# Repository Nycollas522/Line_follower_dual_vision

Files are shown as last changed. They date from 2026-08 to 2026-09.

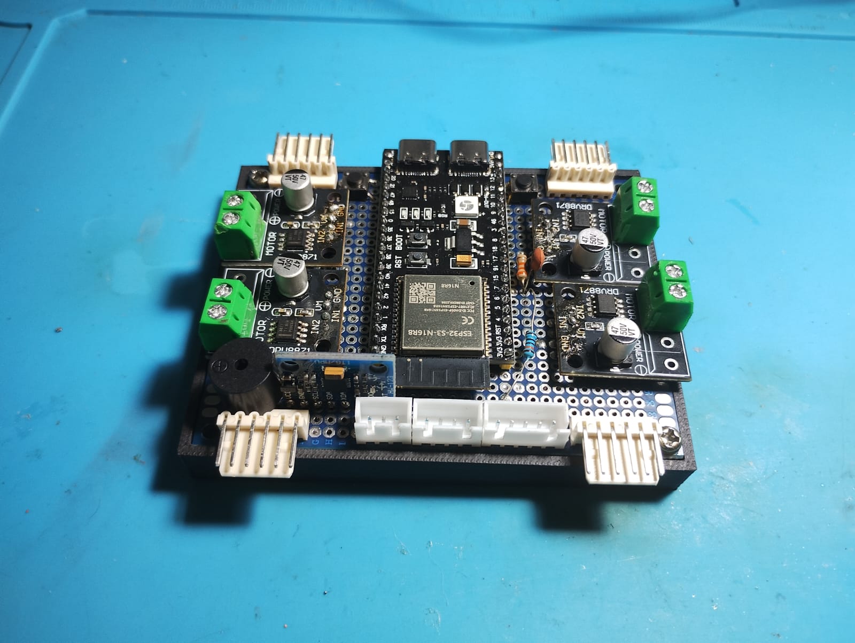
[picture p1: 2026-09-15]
Eletronica/Placa_Inicial/PCB_Superior.jpeg

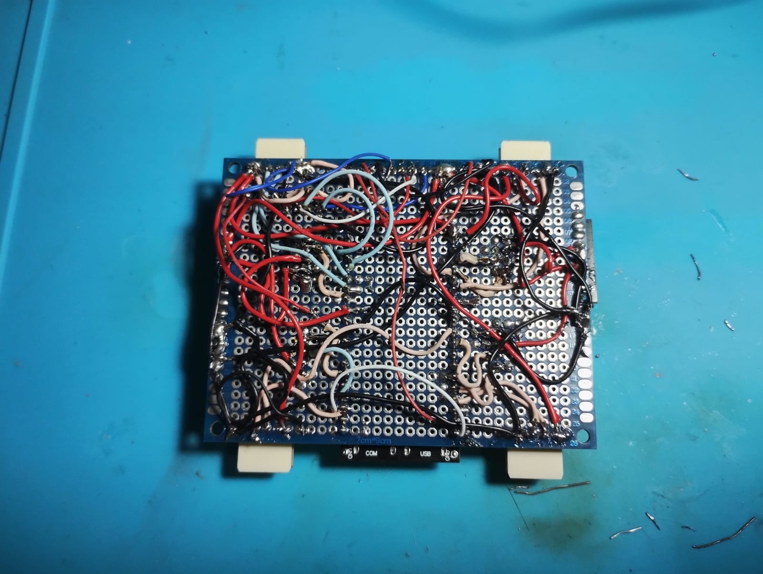
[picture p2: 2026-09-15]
Eletronica/Placa_Inicial/PCB_Inferior.jpeg

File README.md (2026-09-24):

# Line Follower — Visão Dupla

Robô seguidor de linha com **chassi mecanum 4x4** e **duas câmeras**:
uma inferior apontada para o chão, que é a percepção primária do laço
rápido, e uma superior num servo, que serve de aviso antecipado de
curva.

O processamento é dividido em dois: a **Raspberry Pi 5** roda visão e
controle em ROS 2 Jazzy; o **ESP32-S3** fecha o laço de velocidade de
cada roda a 100 Hz e é quem corta os motores se a comunicação cair.

---

## Organização

| pasta | conteúdo |
|---|---|
| **[`Softwares/`](Softwares/)** | Firmware do ESP32-S3 e a pilha ROS 2. Para operar: [guia de operação](Softwares/ros2_ws/OPERACAO.md). Arquitetura e histórico: [README técnico](Softwares/ros2_ws/README.md). |
| [`Eletronica/`](Eletronica/) | Placas e esquemáticos |
| [`Mecanica/`](Mecanica/) | Chassi e modelos CAD |

---

## Especificações

### Chassi

| grandeza | valor |
|---|---|
| Entre-eixos | 176 mm |
| Bitola | 154 mm |
| Diâmetro da roda mecanum | 78 mm |
| Raio mínimo de arco | 165 mm |

### Eletrônica

- **Raspberry Pi 5** — visão e controle (ROS 2 Jazzy)
- **ESP32-S3** — controle de baixo nível, PID por roda a 100 Hz
- 2× câmera CSI (OV5647)
- Servo de pan para a câmera superior
- IMU MPU6050 e display OLED SSD1306
- Bateria LiPo 3S

### Percepção

A **câmera inferior** aponta reto para baixo, 132 mm à frente do centro
cinemático. A vista é ortográfica: a fita mede a mesma largura em toda a
profundidade do quadro, o que simplifica a calibração e torna o erro
lateral uma medida direta em milímetros.

A **câmera superior** enxerga de 20,5 a 54,5 cm à frente. Ela **não** é
referência de direção — é sensor de aviso: nas corridas instrumentadas
antecipou 17 de 23 quebras, com 1,5 a 3,4 s de folga.

---

## Modos de operação

Escolhidos no **menu do OLED do ESP32**. Como a Pi sobe sozinha no boot,
essa é a única interface que existe sem um PC por perto.

| modo | quem dirige | percepção | câmeras |
|---|---|---|---|
| **Parado** | ninguém | desligada | publicando |
| **Seguidor** | seguidor de linha | ligada | publicando |
| **RC** | joystick (DualShock 4) | desligada | publicando |

As câmeras publicam nos três modos de propósito: permite acompanhar a
imagem por `rqt` de um PC externo mesmo dirigindo na mão.

> Escolher um modo **nunca arma a autonomia**. Modo diz quem tem
> autoridade; armar é um ato separado.

Trocar de modo pelo ROS, perfis de velocidade (SUAVE / MÉDIA / RÁPIDA) e o
resto da operação: [guia de operação](Softwares/ros2_ws/OPERACAO.md).

---

## Resultados medidos

Corrida de 3 minutos na pista, com telemetria completa
([dados](Softwares/ros2_ws/dados/)):

```
21,1 m percorridos          99,77% de quadros válidos
erro lateral mediano 8,4 mm       perdas: 0,41 s (0,23% do tempo)
19 quebras atravessadas, 2 travadas
```

### O limite físico das quebras

Uma quebra de ângulo Δ exige um desvio lateral de `R·(1/cos(Δ/2) − 1)`,
onde `R` é o raio mínimo de arco. Somando o erro de rastreio típico e
comparando com a margem lateral da câmera, sai um **limite de 57,8°**.

Validado em duas corridas independentes: **toda** quebra acima desse
ângulo travou, e nenhuma abaixo dele travou na primeira corrida.
Levantar a câmera inferior de 87 para 110 mm elevaria o limite para
70,1° — é margem lateral, não potência, que limita a curva.

---

## Rodando

No robô, a pilha **sobe sozinha no boot** (`robo.service`) em modo Parado.
Ligar, parar, reiniciar, trocar de modo, rodar uma corrida e resetar:
**[guia de operação](Softwares/ros2_ws/OPERACAO.md)**.

Primeira instalação (workspace novo):

```bash
cd Softwares/ros2_ws
colcon build --symlink-install
source install/setup.bash
ros2 launch robot_bringup line_follower.launch.py serial:=true   # so sem o robo.service no ar
```

> ⚠️ **Este robô anda de verdade.** Antes de armar a autonomia, garanta
> espaço livre e saiba como pará-lo
> ([guia, seção 1](Softwares/ros2_ws/OPERACAO.md#1-parar-o-robô-agora)).

O [guia completo](Softwares/ros2_ws/README.md) tem calibração geométrica,
tabela de diagnóstico sintoma → causa → ajuste, as armadilhas já
descobertas nesta bancada e o histórico de correções com os números que
as motivaram.

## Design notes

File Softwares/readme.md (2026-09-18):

# Softwares

Todo o software do robô: firmware do ESP32-S3 e a pilha ROS 2 da
Raspberry Pi.

| pasta | o que é |
|---|---|
| **[`Firmware_Ippo/`](Firmware_Ippo/)** | Firmware do ESP32-S3 (PlatformIO/Arduino). Controle das rodas a 100 Hz, PID por roda, odometria com IMU, menu no OLED, protocolo serial. |
| **[`ros2_ws/`](ros2_ws/)** | Pilha ROS 2 Jazzy. Percepção das duas câmeras, controlador do seguidor, ponte serial, servo da cabeça, modo RC por joystick. |
| **[`ros2_ws/README.md`](ros2_ws/README.md)** | **Guia completo de operação e depuração.** Comece por aqui. |
| [`ros2_ws/dados/`](ros2_ws/dados/) | CSVs de corrida que sustentam os números citados na documentação. |
| [`Codigos_antigos/`](Codigos_antigos/) | Versões anteriores, só como registro. Nada aqui roda no robô atual. |

> ⚠️ **Este robô anda de verdade.** Antes de habilitar a autonomia,
> garanta espaço livre e saiba onde está o STOP. Veja a seção
> "Parar tudo, agora" no guia.

## Em um parágrafo

Chassi mecanum 4x4. A **câmera inferior** aponta reto para baixo e é a
percepção primária do laço rápido; a **superior** fica num servo e serve
de aviso antecipado de curva, não de referência de direção. A Raspberry
Pi roda a visão e o controle; o **ESP32-S3** fecha o laço de velocidade
de cada roda a 100 Hz e é quem corta os motores se a comunicação cair.

O modo de operação (**parado / seguidor / RC**) é escolhido no **menu do
OLED do ESP32** — com o Pi subindo sozinho no boot, essa é a única
interface que existe sem um PC por perto.

## Estrutura mínima para rodar

```bash
cd ros2_ws
colcon build --symlink-install
source install/setup.bash
ros2 launch robot_bringup line_follower.launch.py serial:=true
```

O guia em [`ros2_ws/README.md`](ros2_ws/README.md) tem o resto: calibração
geométrica, tabela de diagnóstico sintoma → causa → ajuste, armadilhas
conhecidas desta bancada e o histórico de correções com os números que
as motivaram.

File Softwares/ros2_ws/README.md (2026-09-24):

# Line Follower — Visão Dupla (ROS 2 Jazzy + ESP32)

Robô seguidor de linha com chassi mecanum 4x4, câmera inferior (percepção
primária) + câmera superior em servo (preview/antecipação), controlado por
Raspberry Pi (ROS 2 Jazzy) com interface de baixo nível num ESP32-S3.

> 📘 **Para operar o robô, use o [OPERACAO.md](OPERACAO.md)**: parar,
> ligar/parar/reiniciar a pilha, trocar de modo pelo menu e pelo ROS,
> armar a autonomia, perfil de velocidade, menu do ESP32, resets, gravar
> firmware e calibrações — conferido contra o código em 24/09/2026.
> Este README guarda arquitetura, parâmetros, depuração e histórico; onde
> os dois divergirem, **vale o OPERACAO.md**.

> ⚠️ **Este robô anda de verdade.** Antes de habilitar autonomia, garanta
> espaço livre, esteja de olho no robô e saiba como pará-lo
> ([OPERACAO.md §1](OPERACAO.md#1-parar-o-robô-agora)). O **B1 longo** no
> ESP32 para e trava os motores (firmware de 24/09/2026 em diante).

---

## Sumário

- [**Próxima sessão — checklist**](#próxima-sessão--checklist)
- [Arquitetura em um parágrafo](#arquitetura-em-um-parágrafo)
- [Diagrama de nós e tópicos](#diagrama-de-nós-e-tópicos)
- [Estrutura do repositório](#estrutura-do-repositório)
- [Build](#build)
- [Subir o sistema](#subir-o-sistema)
- [Parar tudo, agora](#parar-tudo-agora)
- [Ligar/desligar autonomia (do jeito confiável)](#ligardesligar-autonomia-do-jeito-confiável)
- [Modo bancada — mexer na cabeça sem o robô sair andando](#modo-bancada--mexer-na-cabeça-sem-o-robô-sair-andando)
- [Modos de operação (escolhidos no menu do ESP32)](#modos-de-operação-escolhidos-no-menu-do-esp32)
- [Ligar sozinho no boot (systemd)](#ligar-sozinho-no-boot-systemd)
- [Modo RC (joystick DualShock 4)](#modo-rc-joystick-dualshock-4)
- [Teleoperação](#teleoperação)
- [Tabela de tópicos](#tabela-de-tópicos)
- [Protocolo serial (Pi ↔ ESP32)](#protocolo-serial-pi--esp32)
- [Parâmetros — referência completa](#parâmetros--referência-completa)
- [Comandos de depuração](#comandos-de-depuração)
- [Scripts de teste prontos](#scripts-de-teste-prontos)
- [Gravar e reproduzir dados (rosbag)](#gravar-e-reproduzir-dados-rosbag)
- [Plano de testes incremental](#plano-de-testes-incremental)
- [Tabela de diagnóstico (sintoma → causa → ajuste)](#tabela-de-diagnóstico-sintoma--causa--ajuste)
- [Armadilhas conhecidas desta stack](#armadilhas-conhecidas-desta-stack)
- [Testes automatizados (pytest)](#testes-automatizados-pytest)
- [Convenções de sinal](#convenções-de-sinal)
- [Geometria e calibração física](#geometria-e-calibração-física)
- [Histórico de correções relevantes](#histórico-de-correções-relevantes)

---

## Próxima sessão — checklist

Estado ao fechar 10/09/2026: **2 voltas completas na pista**, 160 testes
passando, pilha em modo bancada. Últimos dados em
`logs/corrida_20260910_203230.csv`.

### 1. Rodas — o único achado sem explicação (fazer PRIMEIRO)

O lado direito lê **parado 2.3× mais** que o esquerdo quando a cinemática
pede acima de 0.12 m/s:

```
FL   6.08%      FR  12.73%
RL   5.12%      RR  13.38%
```

Não é quantização de encoder (episódios de 200–400 ms, alguns de 1.9 s) e
não é zona morta (é *pior* em 0.12–0.18 m/s do que em 0.05–0.08). Está
**idêntico nas duas corridas de 3 min** (14.67% e 14.58%), então não veio
de nenhuma mudança recente. Este robô já escondeu mau contato em duas
rodas por um dia inteiro.

```bash
# RODAS SUSPENSAS -- isola tração de atrito com o chão. ~2 min.
python3 scripts/teste_rodas.py
```

Não tirar conclusão sem esse teste. O sintoma na pista ("guiada um pouco
mais ruidosa") é fraco demais para acusar hardware sozinho.

### 2. Decidir o limite de quebra

Modelo validado com **n=6 em duas corridas**: toda quebra acima de
**57.8°** travou, e nenhuma abaixo travou na primeira corrida.

```
limite = 2·acos( 1 / ((margem − erro_rastreio)/R + 1) )
R = wheel_base_k / arc_ratio = 0.165 m      erro_rastreio ≈ 8.4 mm (p50)
```

| margem | altura da inferior | limite |
|---|---|---|
| 31.9 mm | 87 mm (hoje) | **57.8°** |
| 45.0 mm | ~110 mm | **70.1°** |

Decisão do operador foi **não** subir a câmera e usar a quebra fechada
como teste de reencontro. Se mudar de ideia, é só remontagem +
recalibração (`depth_*`, `width_*`, `roi_bottom`) — nenhuma linha de
código.

### 3. A superior: aviso, não reencontro

Medido: no vértice a pista **já saiu do campo dela** (20.5 a 54.5 cm à
frente). Virar a cabeça não traz de volta o que não está lá — confirmado
com o robô parado na quebra, inferior lendo +21.4° com 5/5 bandas e a
superior em SEM LINHA com a cabeça em +15.4°.

Onde ela ganha o lugar dela: **avisou 17 de 23 quebras, 1.5 a 3.4 s
antes**. Planejar em cima disso, não de reencontro no vértice.

Se for investigar: o alvo é a ROI e o alcance dela, não ganho de
controlador.

### 4. Pista

Quebras acima de ~63° são fisicamente impossíveis para este chassi na
margem atual. Suavizá-las é a alternativa a subir a câmera.

### Antes de qualquer medição — as três armadilhas de 10/09/2026

1. **`/head/request` tem dois publicadores.** Cale o seguidor com
   `head_control_enabled: false` antes de comandar a cabeça, ou o servo
   vai ser disputado. Já produziu um diagnóstico de hardware falso.
2. **`/servo/state` é eco do comando**, não posição. A prova de que o
   servo girou é a IMAGEM (`logs/servo_prova.py`).
3. **Taxa derivada de log só vale se log e laço tiverem a mesma taxa.**
   O CSV grava a ~123 Hz e o controle roda a 50 Hz; derivar direto
   inflou a aceleração de 0.857 para 1.485 m/s². Reamostre a 20 ms.

E uma quarta, geral: **compare medições da mesma cena**. Duas leituras da
superior na "mesma" posição deram 287/287 e 0/14 porque o robô foi movido
entre elas. Grave o `heading` da inferior junto de tudo — foi ele que
denunciou.

---

## Arquitetura em um parágrafo

A câmera **inferior** é a referência primária e única fonte de direção no
modo normal — ela está a poucos centímetros da linha e enxerga só ~10 cm à
frente. A câmera **superior**, no servo, nunca comanda o corpo diretamente:
ela só antecipa (reduz velocidade antes de uma curva/quina, ou dá
feedforward saturado e limitado) e ajuda a buscar a linha quando ela se
perde. Cada tópico de comando físico (`/cmd_vel_auto`, `/servo/command`) tem
**um único publicador** no sistema — isso é verificado nos testes e é a
regra de segurança mais importante deste projeto.

## Diagrama de nós e tópicos

```
cam_bottom ──► line_perception_bottom ──► /line/detection ─────┐
                                                                 │
cam_front ───► line_perception_front ───► /line_front/detection┤
                                                                 ▼
                                          ┌──────────────────────────────┐
/odom ────────────────────────────────►  │      line_follower_node      │
/servo/state ─────────────────────────►  │  (ÚNICO publicador de        │
/autonomy/state, /controle/enable ────►  │   /cmd_vel_auto)             │
                                          └───────┬──────────┬───────────┘
                                   /cmd_vel_auto  │          │ /head/request
                                                  ▼          ▼
                                    ┌─────────────────┐  ┌──────────────────┐
                                    │ motor_serial_node│  │ head_servo_node  │
                                    │ (ponte serial +  │  │ (ÚNICO publicador│
                                    │  árbitro teleop) │  │  de /servo/      │
                                    └────────┬─────────┘  │  command)        │
                                             serial        └──────┬───────────┘
                                              ▼                   │
                                          ┌────────┐   /servo/command
                                          │ ESP32-S3│◄─────────────┘
                                          └────────┘
```

`/cmd_vel` (teleop) entra direto em `motor_serial_node`, que arbitra entre
teleop e autonomia via `/autonomy/state`. Veja a [tabela de
tópicos](#tabela-de-tópicos) completa mais abaixo.

## Estrutura do repositório

```
ros2_ws/
├── src/
│   ├── line_msgs/                  # mensagens custom (interfaces)
│   │   └── msg/
│   │       ├── LineDetection.msg    # saida de percepcao (por camera)
│   │       ├── FollowerStatus.msg   # estado do supervisor (telemetria/IC)
│   │       └── HeadRequest.msg      # pedido de apontamento do servo
│   │
│   └── robot_bringup/
│       ├── config/line_follower.yaml   # TODOS os parametros, comentados
│       ├── launch/line_follower.launch.py
│       ├── robot_bringup/
│       │   ├── line_geometry.py        # deteccao pura (sem ROS, testavel)
│       │   ├── line_controller.py      # lei de controle + FSM (sem ROS)
│       │   ├── line_perception_node.py # no ROS: 1 processo por camera
│       │   ├── line_follower_node.py   # supervisor: unico pub /cmd_vel_auto
│       │   ├── head_servo_node.py      # unico pub /servo/command
│       │   └── motor_serial_node.py    # ponte serial + arbitro teleop/auto
│       └── test/
│           ├── test_line_geometry.py    # pytest puro (sem robo/camera)
│           └── test_line_controller.py  # pytest puro (sem robo/camera)
│
├── src/camera_ros/, src/libcamera/     # dependencias de terceiros (vendored)
└── build/, install/, log/              # gerados pelo colcon (nao versionar)
```

Firmware do ESP32-S3 (protocolo serial, PID de roda, encoders, IMU, menu
físico) fica num repositório/pasta separado (`Firmware_Ippo`), compilado
via PlatformIO. Este README cobre o lado ROS 2; o protocolo entre os dois
está documentado na seção [Protocolo serial](#protocolo-serial-pi--esp32).

## Build

```bash
cd ~/ros2_ws
source /opt/ros/jazzy/setup.bash
colcon build --packages-select line_msgs robot_bringup --symlink-install
source install/setup.bash
```

`--symlink-install` é importante: os `.py` do pacote ficam **linkados** ao
código-fonte, então editar um nó e reiniciar o processo já basta — não
precisa rebuildar para toda mudança de lógica Python (só quando muda algo em
`line_msgs` ou `setup.py`/`package.xml`).

Depois de qualquer `git pull`/edição, sempre:

```bash
colcon build --packages-select line_msgs robot_bringup --symlink-install && source install/setup.bash
```

## Subir o sistema

> ⚠️ **A pilha já sobe sozinha no boot pelo `robo.service`.** Com o serviço
> no ar, **não rode `ros2 launch`**: duas instâncias disputam as câmeras e
> a serial. Ligar, parar e reiniciar: `sudo systemctl start|stop|restart
> robo` ([OPERACAO.md §2](OPERACAO.md#2-a-pilha-ros-ligar-parar-reiniciar)).
> Os comandos abaixo são para depuração, **com o serviço parado**.

```bash
# sistema completo (2 cameras + percepcao + controle + servo + serial)
ros2 launch robot_bringup line_follower.launch.py

# porta serial diferente
ros2 launch robot_bringup line_follower.launch.py port:=/dev/ttyUSB0

# validar visao SEM mover o robo (motores nao recebem nada)
ros2 launch robot_bringup line_follower.launch.py serial:=false

# sem a camera superior/servo (so seguimento basico com a inferior)
ros2 launch robot_bringup line_follower.launch.py preview:=false

# sem nenhuma camera (util pra tocar rosbag gravado)
ros2 launch robot_bringup line_follower.launch.py cameras:=false serial:=false
```

Argumentos do launch: `params_file`, `cameras` (`true`/`false`), `serial`,
`preview`, `port`. Todos com default sensato — normalmente só `port:=` muda.

Ao subir, os 10 nós esperados são: `camera_bottom`, `camera_front`,
`line_perception_bottom`, `line_perception_front`, `line_follower_node`,
`head_servo_node`, `motor_serial_node`, `mode_manager_node`, `joy_node`,
`joy_teleop_node`.

```bash
ros2 node list
```

## Parar tudo, agora

O sistema já tem 3 camadas de segurança independentes, mas se precisar
agir manualmente:

```bash
# 1) Zera o comando publicado (autonomia OU teleop, o que estiver ativo)
ros2 topic pub --once /cmd_vel geometry_msgs/msg/Twist "{}"

# 2) Desliga a autonomia (o robo passa a obedecer so /cmd_vel, que esta zerado)
ros2 topic pub --once /controle/enable std_msgs/msg/Bool "{data: false}"

# 3) Ultimo recurso: para a pilha. Sem TWIST, o watchdog do ESP32 zera
#    os motores em 200 ms. NAO use pkill: o robo.service (Restart=on-failure)
#    sobe tudo de novo 10 s depois.
sudo systemctl stop robo
```

Mais rápido, no próprio robô: menu **MODO → Parado → B2 curto** (o Pi
sempre desarma ao sair do SEGUIDOR). Numa corrida, **Ctrl-C** na
`corrida.py`.

Redundâncias já embutidas no sistema (não dependem de você digitar nada):
- **Firmware do ESP32**: para os motores se não chegar `TWIST` novo em 200 ms.
- **`motor_serial_node`**: zera comando se não chegar `/cmd_vel`/`/cmd_vel_auto`
  novo em `cmd_timeout` (0.30 s).
- **`line_follower_node`**: se a câmera inferior parar de publicar ou a
  confiança cair, o supervisor desacelera → recupera → para sozinho
  (`RECOVERING` → `SAFE_STOP`), nunca avança "as cegas". Em `SAFE_STOP` o
  corpo fica parado mas a **cabeça continua varrendo**, procurando a
  linha (`scan_in_safe_stop`).
- **B1 longo no ESP32**: para os motores e **trava** (ignora `TWIST`) até
  alguém rearmar ou entrar em SEGUIDOR/RC; o Pi recebe `MENU,STOP`,
  desarma e vai para PARADO. Funciona mesmo com o ROS travado (o robô
  fica parado). TESTES → CONTROLE ROS alterna a autonomia.

## Ligar/desligar autonomia (do jeito confiável)

⚠️ **Não use só `ros2 topic pub --once` para autonomia.** Em testes reais,
o `--once` às vezes dispara antes de todos os assinantes (`line_follower_
node`, `head_servo_node`, `motor_serial_node`) terminarem a descoberta DDS,
e a mensagem chega só em parte deles. Ver [Armadilhas
conhecidas](#armadilhas-conhecidas-desta-stack).

**Jeito robusto (recomendado)** — publica em burst e confirma:

```bash
ros2 topic pub -r 15 /controle/enable std_msgs/msg/Bool "{data: true}" &
PUBPID=$!
sleep 1.5
kill $PUBPID; wait $PUBPID 2>/dev/null

# confirma que pegou nos 3 nos
ros2 topic echo /autonomy/state --once
```

**Jeito simples**, aceitável se você reenviar e confirmar o resultado:

```bash
ros2 topic pub --once /controle/enable std_msgs/msg/Bool "{data: true}"
sleep 0.5
ros2 topic echo /autonomy/state --once   # confirme que virou "true"
```

Para desligar, o mesmo padrão com `{data: false}`.

**Nunca** deixe um `ros2 topic pub -r ...` correndo em background entre
comandos do terminal sem matá-lo explicitamente — um publisher esquecido
brigando com o próximo comando que você mandar é a causa mais provável de
"o robô não respeita o enable/disable que eu mandei".

## Modo bancada — mexer na cabeça sem o robô sair andando

O `head_servo_node` só aceita comando com a **autonomia ligada**, e ligar
a autonomia normalmente faz o `line_follower_node` publicar `cmd_vel` —
ou seja, o robô anda. Para testar servo/percepção com o robô no chão e
os motores energizados, suspenda só o corpo:

```bash
ros2 param set /line_follower_node body_control_enabled false
ros2 param get /line_follower_node body_control_enabled   # confirme: False
```

Com isso o seguidor para de publicar `cmd_vel` e a ausência de comando
faz o **watchdog do ESP32 parar os motores** — o lado seguro da falha.
A cabeça continua funcionando normalmente.

⚠️ **Isto é conveniência de teste, não trava de segurança.** Não
substitui cortar a tensão dos motores. Se o teste for arriscado, corte a
tensão.

As **paradas de segurança continuam passando** mesmo em modo bancada: na
troca de estado da autonomia e no shutdown o nó publica um `Twist()`
zerado de propósito, para o robô parar. Se você estiver monitorando
`cmd_vel_auto` para conferir que nada se move, ignore os twists zerados e
observe só os que têm velocidade real:

```bash
# so mostra comando que faria o robo andar
ros2 topic echo /cmd_vel_auto | grep -A1 'linear' | grep -v '0\.0'
```

Para devolver o corpo:

```bash
ros2 param set /line_follower_node body_control_enabled true
```

Existe o simétrico para a cabeça, quando um diagnóstico externo precisa
assumir `/head/request` sem brigar com o seguidor (que publica a ~50 Hz e
sempre vence a disputa):

```bash
ros2 param set /line_follower_node head_control_enabled false
```

O `scripts/servo_panorama.py` já faz esse handshake sozinho.

## Modos de operação (escolhidos no menu do ESP32)

O robô sobe em **PARADO** e o modo e escolhido no OLED:
**Menu -> Modo de operacao**. Com o Pi ligando sozinho no boot, o ESP32 e
a unica interface que existe sem um PC por perto.

| modo | quem dirige | percepcao | cameras |
|---|---|---|---|
| **PARADO** | ninguem | desligada | **publicando** |
| **SEGUIDOR** | seguidor de linha | ligada | publicando |
| **RC** | joystick | **desligada** | **publicando** |

**As cameras publicam nos tres modos, de proposito**: e o que permite
abrir `rqt` de um PC externo e ver a imagem mesmo dirigindo na mao.

**Trocar de modo nao reinicia nada.** Todos os nos ficam no ar e apenas
mudam de comportamento -- launches separados por modo custariam os ~25 s
de subida da pilha a cada troca, e derrubariam as cameras junto.

A percepcao nao apenas ignora os quadros: ela **cancela a inscricao** na
camera. Medido em 18/09/2026 com delta de `/proc` (e nao com
`ps -eo pcpu`, que da a media desde o boot do processo e mascarou o
efeito na primeira tentativa):

```
modo       CPU percepcao   CPU camera   imagem para o rqt
SEGUIDOR           63.4%        35.7%        18.7 Hz
RC                  0.0%        26.9%        27.2 Hz
```

### Escolher um modo NUNCA arma a autonomia

Modo diz **quem tem autoridade**; armar e um ato separado (o toggle de
autonomia no menu, ou o homem-morto do joystick). Um menu em que
"escolher seguidor" faz o robo sair andando e um menu perigoso -- ainda
mais num robo que liga sozinho.

Sair do modo seguidor, por outro lado, **desarma sempre**: desligar
nunca precisa de confirmacao.

### Por fora do OLED

```bash
ros2 topic pub --once /robot/mode_request std_msgs/String "{data: RC}"
ros2 topic echo /robot/mode      # o que esta ativo agora
```

---

## Ligar sozinho no boot (systemd)

```bash
sudo cp /tmp/robo.service /etc/systemd/system/robo.service
sudo systemctl daemon-reload
sudo systemctl enable --now robo.service
systemctl status robo.service
journalctl -u robo.service -f        # ou: tail -f ~/ros2_ws/logs/boot.log
```

O `scripts/iniciar_robo.sh` **espera ate 30 s pela porta serial** antes
de lancar: no boot o CH343 leva um tempo para enumerar no USB, e sem
esperar o `motor_serial_node` sobe, nao acha a porta, e o robo fica sem
atuacao ate alguem reiniciar o servico na mao.

O `KillMode=control-group` do servico existe pelo mesmo motivo do
`gravar.sh`: matar so o launch deixaria cameras orfas segurando o
pipeline do libcamera.

Para desligar o autostart: `sudo systemctl disable --now robo.service`.

---

## Modo RC (joystick DualShock 4)

**O ESP32-S3 NAO pode parear o controle.** Ele tem Bluetooth 5 **LE
apenas**, sem Bluetooth Classic (BR/EDR), e o DualShock 4 e HID sobre
Classic. O ESP32 original conseguia (via Bluepad32); o S3 nao. Por isso
o joystick vive na Raspberry e desce pela serial como `TWIST` comum --
**o firmware nao sabe que existe modo RC, e nao precisa saber**.

### Parear o controle (uma vez so)

Segure **PS + Share** ate a barra de luz piscar rapido, entao:

```bash
bluetoothctl
  scan on
  # anote o MAC do "Wireless Controller"
  pair    <MAC>
  trust   <MAC>     # trust faz reconectar sozinho nas proximas vezes
  connect <MAC>
  quit
ls /dev/input/js0   # tem de existir
```

### Dirigir

```bash
ros2 launch robot_bringup rc.launch.py
```

Sobe so ponte serial, cabeca e joystick -- sem cameras e sem seguidor,
que em modo RC apenas competiriam por CPU e pela autoridade da cabeca.

| controle | funcao |
|---|---|
| **L2 (segurar)** | **homem-morto: sem ele nada se move** |
| analogico esquerdo | Y = frente/tras, X = giro |
| L1 / R1 | translacao lateral (strafe) |
| **R2 (segurar)** | turbo: levanta os limites por `turbo_scale` |
| analogico direito | X = servo da cabeca (pan) |

### Sinais dos eixos: ajuste ao vivo, nao no codigo

A numeracao e a convencao de sinal de cada eixo saem do driver de
joystick, e a montagem fisica das rodas entra junto. Nao ha simetria a
procurar -- cada eixo e independente. Por isso sao parametros com
callback: `ros2 param set` vale NA HORA, sem reiniciar o no.

```bash
ros2 param set /joy_teleop_node invert_vx true      # frente/tras
ros2 param set /joy_teleop_node invert_wz true      # giro
ros2 param set /joy_teleop_node invert_vy true      # strafe L1/R1
ros2 param set /joy_teleop_node invert_servo true   # pan da cabeca
```

O no loga a combinacao a cada troca (`ajustes: vx+ wz+ vy- servo-`).
Achou a certa, grave no YAML.

> Armadilha que custou duas rodadas de teste em 22/09/2026: o codigo
> antigo ja tinha um sinal negativo embutido, entao `invert_*: true`
> reproduzia o comportamento antigo em vez de inverte-lo. E os valores
> eram lidos so no `__init__`, entao `ros2 param set` nao fazia nada --
> o que anulava o motivo de serem parametros. Ambos corrigidos.

O homem-morto nao foi pedido pelo operador, foi incluido de proposito:
analogico com deriva e um robo que sai andando sozinho, e segurar um
gatilho custa menos que perseguir o robo pela sala. Para desligar:
`-p require_deadman:=false`.

### Se os controles vierem trocados

Os indices de eixo e botao sao **parametros**, porque driver e kernel
mudam a numeracao. Veja o que o seu controle manda e ajuste no YAML:

```bash
ros2 topic echo /joy
```

Camadas de parada, da mais rapida para a mais lenta: soltar o L2 zera o
comando na hora; sem `/joy` por `joy_timeout` (0.5 s) o no zera; e sem
`TWIST` por 200 ms o **watchdog do proprio ESP32** corta os motores.

---

## Teleoperação

Sempre disponível, independente do estado da autonomia:

```bash
ros2 run teleop_twist_keyboard teleop_twist_keyboard
# publica em /cmd_vel — so e obedecido quando /autonomy/state == false
```

Para voltar da autonomia para teleop: desligue `/controle/enable` (ver
seção acima). O supervisor zera `/cmd_vel_auto` e centraliza o servo
automaticamente nessa transição.

---

## Tabela de tópicos

| Tópico | Tipo | Publicador (único, quando aplicável) | Assinantes |
|---|---|---|---|
| `/cam_bottom/image_raw` | `sensor_msgs/Image` | `camera_bottom` | `line_perception_bottom` |
| `/cam_front/image_raw` | `sensor_msgs/Image` | `camera_front` | `line_perception_front` |
| `/line/detection` | `line_msgs/LineDetection` | `line_perception_bottom` | `line_follower_node` |
| `/line_front/detection` | `line_msgs/LineDetection` | `line_perception_front` | `line_follower_node`, `head_servo_node` |
| `/line/error`, `/line/heading_error`, `/line/status`, `/line/centroid` | vários | `line_perception_bottom` | compatibilidade/rqt (opcional, `publish_compat_topics`) |
| `/line/debug_image`, `/line/mask` | `sensor_msgs/Image` | `line_perception_bottom` | só publica se alguém assinar (rqt_image_view) |
| `/line_front/debug_image`, `/line_front/mask` | `sensor_msgs/Image` | `line_perception_front` | idem |
| **`/cmd_vel_auto`** | `geometry_msgs/Twist` | **`line_follower_node`** | `motor_serial_node` |
| `/cmd_vel` | `geometry_msgs/Twist` | teleop (usuário) | `motor_serial_node` |
| `/head/request` | `line_msgs/HeadRequest` | `line_follower_node` | `head_servo_node` |
| **`/servo/command`** | `std_msgs/Float32` | **`head_servo_node`** | `motor_serial_node` |
| `/servo/state` | `std_msgs/Float32` | `motor_serial_node` | `line_follower_node`, `head_servo_node` |
| `/controle/enable` | `std_msgs/Bool` | usuário / menu ESP32 (via `motor_serial_node`) | todos |
| `/autonomy/state` | `std_msgs/Bool` | `motor_serial_node` | `line_follower_node`, `head_servo_node` |
| `/follower/status` | `line_msgs/FollowerStatus` | `line_follower_node` | rosbag/depuração |
| `/odom` | `nav_msgs/Odometry` | `motor_serial_node` | `line_follower_node` |
| `/imu/data_raw` | `sensor_msgs/Imu` | `motor_serial_node` | — |
| `/wheel_states`, `/wheel_targets` | `sensor_msgs/JointState` | `motor_serial_node` | rosbag/depuração |
| `/wheel_encoder_ticks`, `/wheel_pwm` | `std_msgs/Int32MultiArray` | `motor_serial_node` | rosbag/depuração |
| `/battery/voltage` | `std_msgs/Float32` | `motor_serial_node` | — |

**Convenção de sinal (igual em todos os tópicos acima):** `+x` = direita do
robô. `lateral_error > 0` = linha à direita. `angular.z (wz) > 0` = giro
anti-horário = **esquerda** (padrão ROS). Servo: `angle_deg > 0` = **direita**
(fisicamente corrigido em `motor_serial_node`, ver [Histórico de
correções](#histórico-de-correções-relevantes)).

## Protocolo serial (Pi ↔ ESP32)

115200 baud, linhas terminadas em `\n`. **Não alterado nesta stack** — é o
contrato com o firmware, tratado como fronteira estável.

**Pi → ESP32:**

| Comando | Formato | Efeito |
|---|---|---|
| `TWIST` | `TWIST,vx,vy,wz\n` | velocidade desejada (m/s, m/s, rad/s) |
| `SERVO` | `SERVO,angulo\n` | ângulo do pan, graus, já com sinal físico corrigido |
| `STOP` | `STOP\n` | zera tudo e para |
| `CONTROL_STATE` | `CONTROL_STATE,0\|1\n` | espelha `/autonomy/state` no firmware (só afeta o OLED, não trava motor) |
| `SET_PID` | `SET_PID,kp,ki,kd\n` | ajusta PID de roda do firmware |
| `SAVE_SETTINGS` | `SAVE_SETTINGS\n` | grava config atual na EEPROM do ESP32 |
| `STATUS` | `STATUS\n` | pede status (IMU, OLED) |

**ESP32 → Pi** (telemetria, a cada `TELEMETRY_MS` = 200 ms):

| Linha | Formato | Vira tópico |
|---|---|---|
| `ENC` | `ENC,t0,t1,t2,t3` | `/wheel_encoder_ticks` |
| `ODOM` | `ODOM,x,y,yaw,vx,vy,wz` | `/odom` |
| `WHEEL` | `WHEEL,v0,v1,v2,v3` | `/wheel_states` |
| `TARGET` | `TARGET,v0,v1,v2,v3` | `/wheel_targets` |
| `PWM` | `PWM,p0,p1,p2,p3` | `/wheel_pwm` |
| `IMU` | `IMU,ax,ay,az,gx,gy,gz` | `/imu/data_raw` |
| `SERVO_STATE` | `SERVO_STATE,angulo` | `/servo/state` (sinal desfeito de volta) |
| `BATT` | `BATT,tensao` | `/battery/voltage` |
| `READY` | `READY,...` | log (reconexão do ESP32) |
| `MENU,CONTROL_TOGGLE` | — | toggle físico do botão → `_set_autonomy()` |

Ordem das rodas em todos os arrays: **FL, FR, RL, RR**.

---

## Parâmetros — referência completa

Todos vivem em `config/line_follower.yaml`, organizados por nó. Os **6
que resolvem 90% dos problemas de controle** estão marcados com ⭐.

### `line_perception_bottom` / `line_perception_front`

Mesmo executável (`line_perception_node`), instâncias diferentes.

| Parâmetro | Bottom | Front | O que faz |
|---|---|---|---|
| `image_topic` | `/cam_bottom/image_raw` | `/cam_front/image_raw` | tópico de entrada |
| `output_namespace` | `/line` | `/line_front` | prefixo dos tópicos de saída |
| `rotate_180` | `true` | `true` | **as duas câmeras estão montadas de cabeça para baixo** |
| `depth_near_m` / `depth_far_m` | `0.1104` / `0.1647` | `0.205` / `0.545` | distância física (m) da ROI, ver [Geometria](#geometria-e-calibração-física) |
| `width_near_m` / `width_far_m` | `0.087` / `0.087` | `0.220` / `0.420` | largura de chão coberta pela imagem, calibrado. **Iguais na inferior**: ela aponta reto para baixo, vista ortográfica |
| `curvature_enabled` | `false` | `true` | **desligada na inferior**: base de profundidade curta demais, ver a seção da montagem |
| `camera_x_offset_m` | `0.0` | `0.0` | deslocamento lateral da câmera vs. eixo do robô |
| `line_width_m` | `0.020` | `0.020` | largura real da fita (meça a sua!) |
| `roi_top` / `roi_bottom` | `0.0` / `0.831` | `0.45` / `1.00` | recorte vertical. Na inferior o corte é **por baixo**: o próprio robô aparece nas 81 linhas mais próximas |
| `work_width` | `160` | `160` | downscale antes de processar (CPU) |
| `bands` | `5` | `5` | nº de faixas horizontais amostradas |
| `min_contrast` | `25.0` | `18.0` | separação mínima linha/fundo |
| `max_white_fraction` | `0.80` | `0.85` | guarda contra quadro uniforme (não separa linha/piso — isso é o `flank_weight`) |
| `flank_weight` | `0.7` | `0.7` | exige candidato mais claro que os vizinhos (pista = fita clara + bordas escuras) |
| `track_weight` / `track_sigma` / `track_memory` | `0.6`/`0.25`/`6` | `0.5`/`0.30`/`4` | continuidade temporal entre frames |
| `max_curvature` | `12.0` | `8.0` | 1/m; acima disso, ajuste é ruído |
| `max_heading_for_curvature` | `0.30` rad | `0.30` rad | acima deste desalinhamento, curvatura é descartada (artefato geométrico, não curva real) |
| `min_bands_for_curvature` | `4` | `4` | mínimo de bandas válidas para tentar ajuste quadrático |
| `publish_compat_topics` | `true` | `true` | publica `/error`, `/status` etc. (rqt) |

### `line_follower_node` — supervisor + controlador

⭐ **Os 6 principais:**

| Parâmetro | Valor | Efeito |
|---|---|---|
| `v_max` | `0.22` | m/s em reta limpa. Suba de 0.02 em 0.02. |
| `v_min` | `0.07` | m/s no pior caso ainda seguindo. Se travar em curva, está baixo demais. |
| `k_lateral` | `9.0` | rad/s por metro de erro lateral. Oscila em reta → baixe. Corta curva por dentro → suba. |
| `k_heading` | `1.6` | ganho de orientação — faz entrar alinhado na curva, não só reagir ao deslocamento. |
| `ref_lateral` | `0.045` | erro (m) que já justifica `v_min`. |
| `ref_curvature` | `6.0` | curvatura (1/m) que já justifica `v_min` — freio de curva. |

**Direção (fino):**

| Parâmetro | Valor | Nota |
|---|---|---|
| `k_damping` | `0.35` | amortecimento derivativo |
| `k_feedforward` | `0.15` | ⚠️ **medido no robô**, não valor de projeto — curvatura da câmera inferior é ruidosa (baseline de 10 cm); valor alto cancelava a correção primária. Não subir sem filtrar curvatura primeiro. |
| `derivative_tau` | `0.08` | s, filtro passa-baixa da derivada |
| `ref_heading` | `0.55` | rad |
| `wz_max` | `2.5` | rad/s, teto absoluto |
| `wz_accel` | `6.0` | rad/s², rampa — casado com o firmware |

**Limite cinemático (chassi mecanum — não mexer sem trocar o chassi):**

| Parâmetro | Valor | Nota |
|---|---|---|
| `wheel_base_k` | `0.165` | m, = `halfL + halfW` do firmware |
| `wheel_max_mps` | `0.70` | m/s máximo por roda |
| `arc_ratio` | `0.80` | 1.0 permitiria roda interna parar; 0.80 dá margem contra inversão de roda. **Raio mínimo de curva = `wheel_base_k / arc_ratio` = 20.6 cm, e isso é CONSTANTE, não muda com a velocidade.** |

**Rampas:** `accel: 0.35`, `decel: 0.60` (m/s²).

**Perda de linha e recuperação:**

| Parâmetro | Valor | Nota |
|---|---|---|
| `confidence_ok` | `0.45` | acima → `FOLLOWING` |
| `confidence_min` | `0.15` | abaixo → detecção ignorada |
| `vision_timeout` | `0.35` | s; medido no robô: câmera tem jitter de até ~230 ms entre frames |
| `coast_time` | `0.20` | s antes de `COASTING` → `RECOVERING` |
| `coast_speed_ratio` | `0.5` | fração de `v_min` mantida no coast |
| `recovery_time` | `3.0` | s de busca antes de `SAFE_STOP` |
| `recovery_wz` | `0.9` | rad/s do giro de busca |
| `relock_frames` | `3` | detecções seguidas para voltar a `FOLLOWING` |
| `scan_in_safe_stop` | `true` | a cabeça **continua varrendo** em `SAFE_STOP`. O corpo já está parado, então varrer é ganho puro de percepção, sem risco de atuação. Medido: num episódio de perda de 9,9 s a cabeça varria só os 3 s de `RECOVERING` e depois esperava cega ~7 s |

**Alinhamento parado (`ALIGNING`) — largado torto:**

| Parâmetro | Valor | Nota |
|---|---|---|
| `align_on_start` | `true` | ao sair de `IDLE` com heading acima do limiar, gira **parado** antes de andar |
| `align_heading_deg` | `18.0` | acima disso, alinha antes de avançar |
| `align_exit_deg` | `7.0` | histerese de saída |
| `align_wz` | `0.9` | rad/s do giro parado. **Não use 0.6**: dá `wheel_base_k·wz = 0,099 m/s`, abaixo do atrito estático — medido, o robô ficou 1,2 s parado comandando giro |
| `align_timeout` | `4.0` | s; nunca fica preso alinhando |
| `align_closed_loop_deg` | `9.0` | até aqui a banda próxima aguenta o giro e a visão decide sozinha |
| `align_overshoot_guard` | `1.25` | ×alvo; teto do giro quando cego |

**Por que este estado existe.** Medido em 09/09/2026: largado a 25° da linha, o robô **não consegue se alinhar andando para frente**. O limite é geométrico, não de ganho: o teto de giro sem inverter roda é `arc_ratio·v/wheel_base_k`, logo a curvatura máxima do caminho é `arc_ratio/wheel_base_k = 4,85 1/m` — raio mínimo de **20,6 cm, constante**, independente da velocidade (desacelerar não aperta a curva). Girar 25° nesse raio custa `R·(1−cos25°) = 19 mm` de desvio lateral, que somado ao offset inicial passa dos ±19 mm da banda mais próxima. Na medição ele atravessou a linha, foi a −49,8 mm e a confiança caiu de 0,88 para 0,03.

⚠️ **O progresso do giro vem do `/odom` (encoders), nunca do `wz` comandado.** Uma versão anterior integrava o comando e, com atrito estático, concluiu que tinha girado enquanto o robô seguia a −23,7° — soltou o robô torto e ele saiu da linha. A visão é critério primário sempre que estiver disponível; a rotação medida só encerra a manobra quando a visão sumiu.

**Autoridade de publicação (bancada / diagnóstico):**

| Parâmetro | Valor | Nota |
|---|---|---|
| `body_control_enabled` | `true` | `false` suspende `cmd_vel` — testa cabeça e percepção com a autonomia ligada sem o robô andar. Ver [Modo bancada](#modo-bancada--mexer-na-cabeça-sem-o-robô-sair-andando). Conveniência de teste, **não** trava de segurança |
| `head_control_enabled` | `true` | `false` cede `/head/request` a um diagnóstico externo. Sem isso o seguidor publica a ~50 Hz e vence qualquer script |

**Câmera superior (preview):**

| Parâmetro | Valor | Nota |
|---|---|---|
| `use_preview` | `true` | **chave-mestra** da câmera superior: `false` desliga os três papéis de uma vez |
| `preview_steering_enabled` | `false` | papel **direção** (κ/heading → `wz`). **Desligado por medição**: com ele ligado o robô perdeu a linha 32% do tempo e o viés de curva chegou a −16 mm; desligado, 0% de perda e viés +0,46 mm |
| `preview_speed_enabled` | `true` | papel **velocidade**: só freia antes da curva. Errar custa tempo, não rastreio |
| `preview_recovery_enabled` | `true` | papel **recuperação**: escolhe o *lado* do giro em `RECOVERING`, nunca a magnitude. É o papel de menor risco e o que mais justifica a segunda câmera |
| `preview_timeout` | `0.40` | s |
| `preview_confidence_min` | `0.40` | |
| `preview_ff_gain` | `0.35` | feedforward de curvatura antecipada — só vale para curva **suave** |
| `preview_heading_gain` | `0.40` | feedforward de heading antecipado — vale para **quina** (reta→reta angulada), onde curvatura explode |
| `preview_ff_max_ratio` | `0.30` | teto do preview (curvatura+heading+bearing somados), fração de `wz_max` — garante que a câmera de cima nunca domina |
| `preview_center_tol_deg` | `8.0` | acima disso, pan não está centrado → preview de imagem não vale como direção |
| `preview_speed_gain` | `1.0` | peso do preview na redução de velocidade |
| `use_servo_bearing` | `false` | realimenta o ângulo do servo no giro do **corpo**. Reprovado na medição de 09/09/2026. Controla **só** a realimentação — quem move a cabeça é `head_tracking_enabled` |
| `servo_bearing_gain` | `1.2` | rad/s por rad de ângulo do servo (inerte enquanto `use_servo_bearing` for `false`) |
| `head_tracking_enabled` | `true` | a cabeça rastreia a linha (`HeadMode.TRACK` + antecipação geométrica). Vale manter ligada mesmo sem realimentação: a cabeça virada enquadra a curva, alimentando os papéis de velocidade e recuperação |
| `scan_in_recovery` | `true` | cabeça varre durante `RECOVERING` |

**Direção — atraso e amortecimento:**

| Parâmetro | Valor | Nota |
|---|---|---|
| `curvature_eval_distance_m` | `0.085` | **atraso de transporte** do feedforward. A curvatura é ajustada numa janela 3,5–13,5 cm **à frente**, mas `ω = v·κ` vale para a curvatura *sob* o robô. Sem isto ele vira antes de chegar na curva e entra por dentro |
| `curvature_delay_max_s` | `1.5` | teto do atraso (protege contra `v → 0`) |
| `heading_gain_scheduling` | `true` | agenda `k_heading` para manter o amortecimento constante com a velocidade |
| `target_damping` | `1.0` | ζ alvo; 1,0 = crítico, sem sobressinal |

**O sintoma que o atraso resolve.** Medido: em `t=1,00 s` a curvatura já marcava +0,45 e o `wz` já virava à direita, mas o heading da linha ainda era +0,6° — **o robô continuava na reta**. Ele saía por dentro (`lat` chegou a −34,5 mm) e só então o feedback puxava à esquerda. Na pista isso se vê como *"virou para a esquerda numa curva para a direita"* — o giro à esquerda é a reação, não a causa.

**Por que agendar `k_heading`.** A dinâmica de duas variáveis (`ė = v·θ`, `θ̇ = wz`) com esta lei dá:

```
ë + (k_heading + k_damping·v)·ė + v·k_lateral·e = 0
ωn = √(v·k_lateral)      ζ = (k_heading + k_damping·v) / (2·√(v·k_lateral))
```

Com `k_heading` fixo o amortecimento **cai conforme o robô acelera** — justamente na reta, que é onde ele acelera:

| v (m/s) | ζ sem agendamento | comportamento |
|---|---|---|
| 0,07 | 1,02 | crítico |
| 0,15 | 0,71 | sobressinal ~4% |
| 0,22 | 0,60 | sobressinal ~9,5% |

O agendamento nunca reduz `k_heading` abaixo do valor base, então baixa velocidade fica idêntica.

### `head_servo_node`

| Parâmetro | Valor | Nota |
|---|---|---|
| `max_angle_deg` | `45.0` | limite útil do pan (firmware satura em 90, mas não ajuda ir até lá) |
| `max_rate_deg_s` | `60.0` | |
| `center_rate_deg_s` | `25.0` | taxa reduzida ao voltar/ficar no centro |
| `scan_amplitude_deg` | `35.0` | |
| `scan_rate_deg_s` | `40.0` | |
| `center_deadband_deg` | `0.3` | não reenvia comando se mudou menos que isso |
| `request_timeout` | `0.5` | s; sem `/head/request` novo → volta ao centro |
| `rate_hz` | `40.0` | ⚠️ **precisa reiniciar o nó para mudar** (recria o timer). 40, não 20: o PWM físico do servo roda a 50 Hz — mandar alvo novo com menos frequência que isso é visível como movimento em passos. |
| `track_gain_deg_s_per_m` | `300.0` | `MODE_TRACK`: taxa de giro (°/s) proporcional ao erro lateral (m) da câmera superior |
| `track_confidence_min` | `0.40` | |
| `track_timeout` | `0.40` | s |
| `track_filter_alpha` | `0.45` | filtro passa-baixa no erro antes de virar taxa; menor = mais suave e mais lag, maior = mais responsivo e mais "passos" |

Todos acima **exceto `rate_hz`** têm callback de parâmetros — mudam ao vivo
com `ros2 param set`, sem reiniciar nada.

### `motor_serial_node`

| Parâmetro | Valor | Nota |
|---|---|---|
| `port` | `/dev/ttyACM0` | |
| `baudrate` | `115200` | |
| `max_vx` / `max_vy` / `max_wz` | `0.45` / `0.45` / `2.5` | barreira final, depois de qualquer controlador |
| `cmd_timeout` | `0.30` | s; watchdog do lado do Pi (o firmware tem o seu próprio, 200 ms) |
| `serial_read_rate` | `50.0` | Hz; ⚠️ **não subir**: a 200 Hz este nó sozinho consumia ~40% de uma CPU do Pi e derrubava o FPS das câmeras por contenção de escalonamento |
| `twist_rate` | `50.0` | Hz de envio de `TWIST` |
| `state_rate` | `5.0` | Hz de publicação de `/autonomy/state` |
| `start_autonomy_enabled` | `false` | |

---

## Comandos de depuração

### Ver tudo de uma vez

```bash
ros2 topic list                     # todos os topicos ativos
ros2 node list                      # todos os nos ativos (7 esperados)
ros2 node info /line_follower_node  # publishers/subscribers de um no
```

### Confirmar que um tópico crítico tem exatamente 1 publicador

Isso é a garantia de segurança mais importante do sistema — vale a pena
verificar sempre que algo parecer estranho:

```bash
python3 -c "
import rclpy
from rclpy.node import Node
rclpy.init()
n = Node('pubcheck')
import time
t0 = time.time()
while time.time() - t0 < 3.0:
    rclpy.spin_once(n, timeout_sec=0.1)
for topic in ['/cmd_vel_auto', '/servo/command']:
    info = n.get_publishers_info_by_topic(topic)
    print(topic, '->', len(info), 'publisher(s):', [i.node_name for i in info])
n.destroy_node()
rclpy.shutdown()
"
```

Se aparecer mais de 1, **pare tudo** e investigue (`ros2 node list` +
`pkill` dos processos duplicados) antes de habilitar autonomia.

### Ver a percepção sem mover o robô

```bash
ros2 launch robot_bringup line_follower.launch.py serial:=false

# visual
rqt_image_view   # escolha /line/debug_image ou /line_front/debug_image

# numerico, uma leitura
ros2 topic echo /line/detection --once
ros2 topic echo /line_front/detection --once

# continuo
ros2 topic echo /line/detection
```

Campos-chave em `LineDetection`: `valid`, `confidence`, `lateral_error` (m),
`heading_error` (rad), `curvature` (1/m), `bands_valid`/`bands_total`,
`contrast`, `line_width` (compare com a fita real — é o teste da própria
calibração), `processing_time`, `pipeline_latency`.

### Acompanhar o supervisor em tempo real

```bash
ros2 topic echo /follower/status
```

Campos-chave: `state_name` (`IDLE`/`FOLLOWING`/`DEGRADED`/`COASTING`/
`RECOVERING`/`SAFE_STOP`), `cmd_vx`/`cmd_wz`, `wz_limit` (se `cmd_wz` está
saturado nesse valor, o robô quer virar mais do que o limite cinemático
permite), `severity` (0–1, quanto a velocidade foi reduzida), `vision_age`
(idade da última detecção válida), `loss_events`, `mean_abs_error`.

### FPS e latência das câmeras

`ros2 topic hz` é **pouco confiável nesta stack** (corrida de descoberta
DDS — ver [Armadilhas conhecidas](#armadilhas-conhecidas-desta-stack)).
Prefira medir direto com `rclpy`:

```bash
python3 -c "
import rclpy, time
from sensor_msgs.msg import Image
from rclpy.node import Node
from rclpy.qos import QoSProfile, ReliabilityPolicy, HistoryPolicy
QOS = QoSProfile(reliability=ReliabilityPolicy.BEST_EFFORT, history=HistoryPolicy.KEEP_LAST, depth=1)
rclpy.init()
n = Node('fps_check')
counts = {'bottom': 0, 'front': 0}
n.create_subscription(Image, '/cam_bottom/image_raw', lambda m: counts.__setitem__('bottom', counts['bottom']+1), QOS)
n.create_subscription(Image, '/cam_front/image_raw', lambda m: counts.__setitem__('front', counts['front']+1), QOS)
t0 = time.time()
while time.time() - t0 < 5.0:
    rclpy.spin_once(n, timeout_sec=0.05)
elapsed = time.time() - t0
print(f'bottom: {counts[\"bottom\"]/elapsed:.1f} fps')
print(f'front:  {counts[\"front\"]/elapsed:.1f} fps')
n.destroy_node(); rclpy.shutdown()
"
```

### CPU por processo (se o FPS cair)

```bash
ps -eo pid,pcpu,pmem,etimes,comm --sort=-pcpu | head -12
uptime   # load average; compare com "nproc" (numero de nucleos)
nproc
```

Se algo estiver consumindo CPU de forma desproporcional, o suspeito mais
comum é um timer rodando rápido demais sem necessidade — veja o histórico
de `serial_read_rate` acima.

### Servo — testar isoladamente

⚠️ O watchdog do `head_servo_node` exige `/autonomy/state == true` para
aceitar qualquer modo (`HOLD`/`SCAN`/`TRACK`) — com autonomia desligada ele
sempre força `MODE_CENTER`, mesmo se você mandar outra coisa. Isso é
proposital (cabeça não faz nada sozinha com o corpo desligado), mas
significa que **não dá para testar o servo com o corpo garantidamente
parado** — ligue a autonomia e observe, pronto para desligar rápido.

```bash
python3 -c "
import rclpy, time
from rclpy.node import Node
from rclpy.qos import QoSProfile, ReliabilityPolicy, HistoryPolicy
from std_msgs.msg import Bool, Float32
from line_msgs.msg import HeadRequest
QOS = QoSProfile(reliability=ReliabilityPolicy.RELIABLE, history=HistoryPolicy.KEEP_LAST, depth=10)
rclpy.init()
n = Node('servo_check')
head_pub = n.create_publisher(HeadRequest, '/head/request', QOS)
enable_pub = n.create_publisher(Bool, '/controle/enable', QOS)
angle = [None]
n.create_subscription(Float32, '/servo/state', lambda m: angle.__setitem__(0, m.data), QOS)
deadline = time.time() + 5.0
while time.time() < deadline and enable_pub.get_subscription_count() < 3:
    rclpy.spin_once(n, timeout_sec=0.05)
on = Bool(); on.data = True
for _ in range(10):
    enable_pub.publish(on); rclpy.spin_once(n, timeout_sec=0.05)
time.sleep(0.6)
req = HeadRequest(); req.mode = HeadRequest.MODE_HOLD; req.angle_deg = 25.0
t0 = time.time()
while time.time() - t0 < 3.0:
    head_pub.publish(req); rclpy.spin_once(n, timeout_sec=0.05)
print('servo_angle:', angle[0], '(esperado ~+22 a +25, positivo = direita)')
req.mode = HeadRequest.MODE_CENTER
off = Bool(); off.data = False
for _ in range(20):
    head_pub.publish(req); enable_pub.publish(off); rclpy.spin_once(n, timeout_sec=0.05)
n.destroy_node(); rclpy.shutdown()
"
```

### Testar rodas isoladamente (rodas suspensas)

```bash
# ver ticks acumulados (ordem FL, FR, RL, RR)
ros2 topic echo /wheel_encoder_ticks

# ver velocidade medida / alvo / PWM por roda
ros2 topic echo /wheel_states
ros2 topic echo /wheel_targets
ros2 topic echo /wheel_pwm
```

Gire cada roda à mão: só o índice correspondente deve mudar, e crescer se
girada "para frente". Depois, com o motor: `TWIST,0.08,0,0` (via
`/cmd_vel`) deve dar as 4 velocidades **positivas** em `/wheel_states` — se
alguma vier negativa, é sinal de fiação/`MOTOR_SIGN` invertido naquela
roda, não bug de software.

### Ajustar parâmetro ao vivo

```bash
ros2 param get /line_follower_node k_lateral
ros2 param set /line_follower_node k_lateral 7.0
ros2 param set /line_perception_bottom min_contrast 20.0
ros2 param set /head_servo_node track_filter_alpha 0.30
```

Funciona para praticamente tudo **exceto** `rate_hz` do `head_servo_node`
(precisa reiniciar o nó — o motivo está comentado no próprio código).

---

## Scripts de teste prontos

Scripts `rclpy` autocontidos são mais confiáveis que combinar `ros2 topic
pub`/`echo` na CLI (ver [Armadilhas conhecidas](#armadilhas-conhecidas-desta-stack)).
Salve estes em `scripts/` (crie a pasta) para reusar entre sessões.

### `scripts/live_test.py` — liga, monitora, desliga com garantia

```python
#!/usr/bin/env python3
"""Liga autonomia, monitora /follower/status e /cmd_vel_auto por N
segundos, desliga com confirmacao. Uso: python3 live_test.py [segundos]"""
import sys
import time

import rclpy
from geometry_msgs.msg import Twist
from rclpy.node import Node
from rclpy.qos import HistoryPolicy, QoSProfile, ReliabilityPolicy
from std_msgs.msg import Bool, Float32

from line_msgs.msg import FollowerStatus

QOS = QoSProfile(reliability=ReliabilityPolicy.RELIABLE,
                  history=HistoryPolicy.KEEP_LAST, depth=10)
RUN_SECONDS = float(sys.argv[1]) if len(sys.argv) > 1 else 4.0
EXPECTED_SUBS = 3  # line_follower_node, head_servo_node, motor_serial_node

class LiveTest(Node):
    def __init__(self):
        super().__init__('live_test')
        self.enable_pub = self.create_publisher(Bool, '/controle/enable', QOS)
        self.create_subscription(Twist, '/cmd_vel_auto', self._on_cmd, QOS)
        self.create_subscription(FollowerStatus, '/follower/status', self._on_status, QOS)
        self.create_subscription(Float32, '/servo/state', self._on_servo, QOS)
        self.last_cmd = None
        self.last_status = None
        self.last_servo = None

    def _on_cmd(self, msg):
        self.last_cmd = msg

    def _on_status(self, msg):
        self.last_status = msg

    def _on_servo(self, msg):
        self.last_servo = msg.data

    def wait_subs(self, minimum, timeout_s=5.0):
        deadline = time.time() + timeout_s
        while time.time() < deadline:
            n = self.enable_pub.get_subscription_count()
            if n >= minimum:
                return n
            rclpy.spin_once(self, timeout_sec=0.05)
        return self.enable_pub.get_subscription_count()

    def set_enable(self, value, settle_s=0.5):
        self.wait_subs(EXPECTED_SUBS)
        msg = Bool(); msg.data = value
        for _ in range(5):
            self.enable_pub.publish(msg)
            rclpy.spin_once(self, timeout_sec=0.05)
        end = time.time() + settle_s
        while time.time() < end:
            rclpy.spin_once(self, timeout_sec=0.05)

def main():
    rclpy.init()
    node = LiveTest()
    try:
        node.set_enable(True)
        print(f'>>> AUTONOMIA LIGADA por {RUN_SECONDS:.0f}s -- OBSERVE O ROBO <<<')
        started = time.time()
        while time.time() - started < RUN_SECONDS:
            end = time.time() + 0.5
            while time.time() < end:
                rclpy.spin_once(node, timeout_sec=0.1)
            s, c = node.last_status, node.last_cmd
            if s is not None:
                servo = f'{node.last_servo:+.1f}' if node.last_servo is not None else '?'
                sat = 'SAT' if abs(c.angular.z if c else 0) >= s.wz_limit - 0.01 else '   '
                print(f'  t={time.time()-started:4.1f}s  st={s.state_name:9s} '
                      f'vx={c.linear.x if c else 0:.3f} wz={c.angular.z if c else 0:+.3f} '
                      f'/{s.wz_limit:.3f}{sat}  e={s.lateral_error*1000:+6.1f}mm  '
                      f'servo={servo}deg  sev={s.severity:.2f} conf={s.confidence:.2f}')
    finally:
        print('>>> DESLIGANDO <<<')
        node.set_enable(False, settle_s=0.8)
        node_c = node.last_cmd
        if node_c is not None:
            ok = abs(node_c.linear.x) < 1e-6 and abs(node_c.angular.z) < 1e-6
            print('ROBO PARADO (confirmado)' if ok else 'AVISO: comando nao esta em zero!')
        node.destroy_node()
        rclpy.shutdown()

if __name__ == '__main__':
    main()
```

Uso:

```bash
python3 scripts/live_test.py 5.0   # roda 5s de autonomia com log detalhado
```

### Isolar deriva mecânica vs. controle (teleop puro, sem visão)

Use delta de ticks acumulados (imune a ruído de quantização em baixa
velocidade — **não** use `/wheel_states` instantâneo para isso, ele é
ruidoso a baixas velocidades e pode indicar assimetria que não existe):

```python
#!/usr/bin/env python3
"""python3 straight_isolation.py [duracao_s] [vx]"""
import sys, time
import rclpy
from geometry_msgs.msg import Twist
from rclpy.node import Node
from rclpy.qos import QoSProfile, ReliabilityPolicy, HistoryPolicy
from std_msgs.msg import Int32MultiArray

QOS = QoSProfile(reliability=ReliabilityPolicy.RELIABLE, history=HistoryPolicy.KEEP_LAST, depth=10)
DURATION = float(sys.argv[1]) if len(sys.argv) > 1 else 3.0
VX = float(sys.argv[2]) if len(sys.argv) > 2 else 0.10

rclpy.init()
node = Node('straight_isolation')
cmd_pub = node.create_publisher(Twist, '/cmd_vel', QOS)
ticks = [None]
node.create_subscription(Int32MultiArray, '/wheel_encoder_ticks',
                          lambda m: ticks.__setitem__(0, list(m.data)), QOS)

t0 = time.time()
while time.time() - t0 < 5.0 and cmd_pub.get_subscription_count() < 1:
    rclpy.spin_once(node, timeout_sec=0.05)
while ticks[0] is None:
    rclpy.spin_once(node, timeout_sec=0.05)
before = ticks[0][:]

twist = Twist(); twist.linear.x = VX
t_start = time.time()
while time.time() - t_start < DURATION:
    cmd_pub.publish(twist)
    rclpy.spin_once(node, timeout_sec=0.02)
elapsed = time.time() - t_start

stop = Twist()
for _ in range(15):
    cmd_pub.publish(stop); rclpy.spin_once(node, timeout_sec=0.02)
time.sleep(0.3); rclpy.spin_once(node, timeout_sec=0.2)
after = ticks[0]

ticks_per_m = 330.0 / (3.14159265 * 0.078)  # 330 ticks/rev, roda 7.8cm
names = ['FL', 'FR', 'RL', 'RR']
speeds = [(a - b) / ticks_per_m / elapsed for a, b in zip(after, before)]
for name, v in zip(names, speeds):
    print(f'{name}: {v:+.4f} m/s')
left, right = (speeds[0]+speeds[2])/2, (speeds[1]+speeds[3])/2
print(f'esquerda={left:+.4f}  direita={right:+.4f}  '
      f'diff={abs(right-left)/max(abs((left+right)/2),1e-6)*100:.1f}%')
node.destroy_node(); rclpy.shutdown()
```

Diferença acima de ~8-10% entre lados sugere assimetria mecânica real
(diâmetro de roda, atrito, fiação) — abaixo disso, é ruído normal.

---

## Gravar e reproduzir dados (rosbag)

Para coleta extensa (pista maior, relatório de IC) — melhor que ler em
tempo real, porque não exige confirmação a cada poucos segundos:

```bash
ros2 bag record -o sessao_$(date +%F_%H%M) \
  /follower/status /line/detection /line_front/detection \
  /cmd_vel_auto /odom /servo/state /imu/data_raw \
  /wheel_states /wheel_targets /wheel_pwm /battery/voltage
```

Evite incluir `/line/debug_image`/`/line_front/debug_image` — as imagens
enchem o cartão rápido. Grave essas separadamente e curtas, só quando
precisar depurar visualmente um trecho específico.

Reproduzir depois (sem robô/câmera):

```bash
ros2 launch robot_bringup line_follower.launch.py cameras:=false serial:=false
ros2 bag play sessao_2026-09-09_2200
```

Análise rápida de um bag:

```bash
ros2 bag info sessao_2026-09-09_2200
```

---

## Plano de testes incremental

Sempre nesta ordem — cada etapa assume que a anterior passou.

1. **Rodas suspensas.** `TWIST` manual por `/cmd_vel`, confirme sentido de
   giro nas 4 rodas (`/wheel_states` positivo pra frente).
2. **Validação visual sem mover.** `serial:=false`, `rqt_image_view`,
   confira `line_width` medido contra a fita real.
3. **Sinal do erro.** Mova a mão pela direita da linha:
   `lateral_error > 0` **e** `cmd_wz < 0` em `/follower/status`. Se
   inverteu, pare e investigue antes de qualquer teste no chão.
4. **Reta lenta.** `v_max` baixo (~0.10) primeiro. `mean_abs_error` deve
   ficar de dígito único de mm depois de convergir.
5. **Curva ampla**, depois **curva fechada** — observe `wz` vs `wz_limit`
   (saturado = está no teto cinemático) e `severity`.
6. **Iluminação diferente** — `contrast` deve continuar > `min_contrast`;
   `confidence` > `confidence_ok`.
7. **Perda de 1 frame** (tapar a câmera rapidamente) — deve entrar em
   `COASTING` e voltar a `FOLLOWING` sem parar de todo.
8. **Perda persistente** (tapar por vários segundos) —
   `COASTING → RECOVERING (cabeça varre) → SAFE_STOP`.
9. **Retorno à teleop** — desligar autonomia deve zerar `/cmd_vel_auto` e
   centralizar o servo automaticamente.

Suba a velocidade (`v_max`) só depois que o item anterior estiver limpo.

---

## Tabela de diagnóstico (sintoma → causa → ajuste)

| Sintoma | Observe | Causa provável | Ajuste único | Critério de sucesso |
|---|---|---|---|---|
| Oscila em reta | `cmd_wz` alternando sinal | `k_lateral` alto | `k_lateral` −20% | `mean_abs_error` cai |
| Corta curva por dentro | `heading_error` grande, `wz` pequeno | `k_heading` baixo | `k_heading` +30% | entra alinhado na curva |
| Entra rápido demais na curva | `severity` sobe tarde | `ref_curvature` alto | `ref_curvature` −30% | `cmd_vx` cai antes da curva |
| Trava/para em curva fechada | `cmd_wz == wz_limit` constante | `v_min` baixo, **ou** o raio da curva é menor que `wheel_base_k/arc_ratio` (fisicamente impossível nessa velocidade) | `v_min` +0.02, ou aumentar `arc_ratio` | conclui a curva |
| Gira no lugar em vez de curvar | `wz_limit` muito alto | `arc_ratio` alto | `arc_ratio` → 0.65 | descreve arco, não pirueta |
| Deriva progressiva mesmo em reta | `curvature` alto numa reta conhecida | desalinhamento inicial fazendo curvatura parecer real (artefato geométrico) | confirme `max_heading_for_curvature` ativo; se `heading_error` já estava grande, o problema é físico (posicionamento), não parâmetro | `curvature_valid=false` quando heading é grande |
| Perde em sombra | `contrast` < `min_contrast` | limiar rígido | `min_contrast` −10 | `confidence` > `confidence_ok` volta |
| Pega reflexo em vez da linha | `line_width` reportado ≠ real | continuidade fraca | `track_weight` → 0.8 | `line_width` estável e correto |
| Banda distante cai, mas o contraste está alto | `bands_valid` < total com `contrast` normal | **gradiente de iluminação** (reflexo): um Otsu único não serve os dois extremos da ROI | `background_kernel_ratio` → 3.0 na câmera afetada | `bands_valid` volta ao total, `line_width` não muda |
| `COASTING` sem motivo aparente | `vision_age` perto/acima de `vision_timeout` | jitter de FPS da câmera | `vision_timeout` +0.1 | `loss_events` para de subir |
| Anda "colado" num lado da linha | `lateral_error` com viés constante | câmera fisicamente descentrada | `camera_x_offset_m` | erro médio → perto de 0 |
| Robô para sozinho (`SAFE_STOP`) | `state_name` no bag | perda persistente real | veja `contrast`/`confidence` no trecho anterior | volta a seguir depois de reposicionar |
| FPS de câmera baixo (< 15) | `ps -eo pcpu` no processo da câmera/percepção | CPU do Pi saturada | `work_width` → 128; confira se algum outro nó está consumindo CPU desproporcional | volta a > 20 fps |
| Servo "em passos" | movimento visual | `rate_hz` baixo e/ou filtro fraco | `rate_hz` → 40 (precisa restart) e/ou `track_filter_alpha` −0.1 | movimento visualmente contínuo |
| Servo "lerdo"/atrasado | mesma faixa de `rate_hz` alta, mas resposta lenta | `track_filter_alpha` baixo demais (suaviza demais) | `track_filter_alpha` +0.1~0.15 | resposta mais imediata, ainda sem passos |
| Ao comandar ângulo positivo, servo vai para o lado errado | teste de `MODE_HOLD` com ângulo conhecido | convenção física do servo invertida vs. convenção ROS | conserto já aplicado em `motor_serial_node` — se reaparecer após trocar hardware, inverter de novo lá | `+angulo` físico gira para a **direita** |
| Cabeça não faz nada (fica em 0°) mesmo pedindo `TRACK`/`HOLD` | `/autonomy/state` | watchdog do servo exige autonomia ligada | ligar autonomia (ver seção específica) | servo responde ao pedido |
| Comando de habilitar/desabilitar "não pegou" | `ros2 topic echo /autonomy/state` logo depois | corrida de descoberta DDS num `--once` isolado | use o padrão de burst+confirmação | leitura confirma o valor esperado |
| Cabeça "vira" mas a imagem da superior não muda | compare quadros em ângulos opostos (`logs/servo_prova.py`) | **primeiro suspeite do seu script**: `line_follower_node` publica `/head/request` a 50 Hz e disputa o servo. Só depois, mecânica | `head_control_enabled: false` antes de comandar; `/servo/state` NÃO detecta o problema, é eco do comando | `-35` vs `+35` difere em dezenas de níveis de cinza, não em ~2 |

---

## Armadilhas conhecidas desta stack

Coisas que custaram tempo real de depuração nesta bancada — documentadas
para não repetir o mesmo ciclo.

1. **`ros2 topic pub --once` pode disparar antes de todos os assinantes
   serem descobertos.** Com 3 nós assinando `/controle/enable`, o `--once`
   às vezes entrega a mensagem só a 1 ou 2 deles. Sempre confirme com
   `ros2 topic echo` depois, ou use o padrão de burst (seção [Ligar/
   desligar autonomia](#ligardesligar-autonomia-do-jeito-confiável)).

2. **Processos em background sobrevivem entre comandos de terminais
   diferentes.** Um `ros2 topic pub -r 10 ... &` que você não matou
   explicitamente continua rodando e pode brigar com o próximo comando
   que você mandar minutos depois, causando comportamento aparentemente
   aleatório de enable/disable. Sempre `kill $PID; wait $PID` depois de
   um publisher em background, e cheque com
   `ps -eo pid,args | grep "ros2 topic pub"` se sobrou algo.

3. **`ros2 topic hz`/`ros2 node list` têm cache do daemon `ros2cli` que
   pode ficar visivelmente desatualizado** (nós "fantasma" duplicados
   logo após um restart, por exemplo). Se a saída parecer impossível
   (nó aparecendo 2x, hz vazio com o tópico claramente publicando),
   confirme com um script `rclpy` direto antes de assumir que é bug real.

4. **Parâmetros só mudam ao vivo se o nó tiver
   `add_on_set_parameters_callback` registrado.** Sem isso, `ros2 param
   set` atualiza o valor guardado no servidor de parâmetros mas **não**
   o comportamento do nó (que cacheou o valor antigo num atributo no
   `__init__`). Todos os nós desta stack têm o callback — mas se você
   adicionar um novo parâmetro num nó, lembre de expor no callback
   também, senão o ajuste "ao vivo" é só ilusão.

5. **Velocidade lateral do controlador de roda não muda o raio mínimo de
   curva.** Com o limite `wz_limit = arc_ratio * vx / wheel_base_k`, o
   raio mínimo alcançável é `wheel_base_k / arc_ratio` — **uma constante,
   independente de `vx`** (o `vx` se cancela na razão `vx/wz`). Reduzir a
   velocidade numa curva fechada não ajuda a fazer a curva mais fechada;
   só ajuda a controlar melhor uma curva que já é geometricamente
   possível.

6. **Curvatura estimada por ajuste de bandas explode em dois casos
   comuns:** (a) numa **quina real** (reta que vira reta angulada, sem
   arco entre elas — o ajuste quadrático não tem como representar uma
   dobra), e (b) quando o **próprio robô está desalinhado** (mesmo numa
   reta real, ver a linha de um ângulo faz ela parecer curvar). Os dois
   casos têm o guard `max_heading_for_curvature`; o primeiro também
   ganhou `preview_heading_gain` (usa o ângulo direto, não a curvatura).

7. **Watchdogs de segurança se sobrepõem.** O servo não aceita `TRACK`/
   `HOLD`/`SCAN` sem autonomia ligada; a câmera superior não vale como
   direção sem o pan centrado (a menos que seja `servo_bearing`, que é
   o oposto — só vale **com** o pan girado). Ao testar um comportamento
   isolado, confira se algum desses gates não está silenciosamente
   forçando o resultado que você observa.

---

## Testes automatizados (pytest)

`line_geometry.py` e `line_controller.py` não importam `rclpy` nem `cv2`
no core — são testáveis com Python puro, sem robô, sem câmera:

```bash
cd ~/ros2_ws
source install/setup.bash
python3 -m pytest src/robot_bringup/test/test_line_geometry.py src/robot_bringup/test/test_line_controller.py -v
```

Cobrem: convenção de sinal (erro/heading/curvatura → `wz`), limite
cinemático do mecanum, máquina de estados completa (perda/recuperação/
parada segura), rejeição de curvatura espúria (quina e desalinhamento),
continuidade contra reflexos, feedforward do preview (curvatura + heading
+ bearing do servo, individualmente e combinados, sempre respeitando o
mesmo teto).

Lint (estilo, não cobre nós ROS que exigem hardware):

```bash
python3 -m flake8 --max-line-length 99 --select=E,F,C --extend-ignore=W503 src/robot_bringup/robot_bringup/
```

---

## Convenções de sinal

Válidas em **todo** o sistema, sem exceção — se algo parecer invertido,
o bug está em quem violou a convenção, não na convenção:

| Grandeza | Positivo significa |
|---|---|
| `lateral_error` (m) | linha à **direita** do robô |
| `heading_error` (rad) | linha se afastando inclinada para a **direita** |
| `curvature` (1/m) | pista curvando para a **direita** |
| `angular.z` / `wz` (rad/s) | giro **anti-horário** = **esquerda** (padrão ROS) |
| `angle_deg` do servo (`HeadRequest`, `/servo/state`) | pan apontando para a **direita** |

A tradução `erro positivo (direita) → wz negativo (direita)` acontece
**uma única vez**, em `line_controller.py::_steering()`. Nenhum outro
arquivo deveria precisar inverter sinal de novo — se precisar, é sinal de
que a convenção está sendo violada em algum lugar.

## Geometria e calibração física

Medidas do chassi (do firmware, `Config::HALF_L`/`HALF_W`):

```
Distância entre eixos (frente-trás):     17.6 cm  →  halfL = 8.8 cm
Distância entre rodas (esquerda-direita): 15.4 cm  →  halfW = 7.7 cm
wheel_base_k = halfL + halfW = 16.5 cm  =  0.165 m
Diâmetro das rodas:    7.8 cm
Ticks do encoder:      330 por volta
```

Câmeras (medidas com régua, ver comentários em `line_follower.yaml`):

```
Camera inferior (MONTAGEM NOVA, 10/09/2026): aponta RETO PARA BAIXO,
                 ~87 mm do chao, centro da lente 44 mm a frente do eixo
                 dianteiro (= 132 mm do centro cinematico).
                 Campo: 87.1 x 65.3 mm de chao, escala 7.4 px/mm.
                 ROI (ja sem o robo): 110.4 a 164.7 mm a frente do centro.
Camera superior: 20.5 cm a frente do robo, alcance visivel ~34 cm,
                 no servo (movimento horizontal).
```

### A montagem apontada para baixo — o que muda

**Vista ortográfica.** A fita mede a mesma largura em todas as linhas
(147.0 px perto contra 146.1 px longe — 0.6%, menor que o resíduo de
11.6 px do ajuste). Por isso `width_near_m == width_far_m`. Com a
montagem inclinada antiga a largura crescia com a distância.

**Campo escala 1:1 com a altura** nesta lente (~53° horizontal):
`largura_do_campo_em_mm ≈ altura_da_câmera_em_mm`. Verificado em duas
alturas: 30 mm → campo 30.0 mm; 87 mm → campo 87.1 mm. Use isso para
dimensionar qualquer suporte novo.

**A margem lateral é o que importa.** O detector separa a linha do piso
pelos **flancos escuros dos dois lados**; sem um flanco, ele perde a
referência de uma vez — e como todas as bandas têm a mesma largura, não
há a degradação suave que a montagem inclinada dava (banda próxima
estreita, distantes largas).

| altura | campo | margem/lado (fita 20 mm) | base de profundidade |
|---|---|---|---|
| 30 mm | 30 mm | 5 mm — **perde a linha a qualquer desvio** | 22.5 mm |
| 60 mm | 60 mm | 20 mm | 45 mm |
| **87 mm (atual)** | **87 mm** | **33.6 mm** | **54.5 mm** |
| 100 mm | 100 mm | 40 mm | 75 mm |

**O robô aparece no quadro.** Ocupa as 81 linhas mais próximas (brilho
médio ~50 contra ~120 do piso). Depois do `rotate_180` isso cai na base,
então o corte é `roi_bottom`, não `roi_top`.

**Isso também determina o `rotate_180`.** A parte que mostra o próprio
robô tem de ser a mais *próxima* do campo. No frame cru ela está no topo;
girando 180° vai para a base, que é onde `depth_at(y_ratio=1)` espera a
distância mínima. Como a linha corre na vertical (o que descarta rotações
de 90°), só restavam 0° e 180° — e o robô decide. **Não precisa de teste
com motor para conferir isso.**

**A antecipação passou a vir da montagem.** O erro é medido ~116 mm à
frente do centro, então `e_medido = e_centro + L·θ` e `k_lateral·L = 1.04`
já age como ganho de orientação — dois terços do `k_heading` nominal, de
graça. O controlador desconta isso sozinho (`_ganho_de_heading` lê o
`lookahead_distance` que o detector publica), o que mantém ζ = 1.00 em
toda a faixa de velocidade. Sem descontar ficaria em 1.37–1.66:
sobreamortecido, lento para voltar à linha.

Para recalibrar `width_near_m`/`width_far_m` depois de mudar a montagem
física de uma câmera:

1. Posicione o robô sobre a fita, parado e bem alinhado.
2. Meça a fração da largura da imagem que a fita ocupa nas bandas mais
   próxima e mais distante (via `/line/debug_image` ou analisando um
   frame salvo). Numa montagem apontada para baixo as duas dão o mesmo
   valor — se derem diferente, a câmera não está vertical.
3. `largura_de_chão = largura_real_da_fita / fração_ocupada` — aplique
   essa conta nas bandas próxima e distante para obter
   `width_near_m`/`width_far_m`.
4. Confira: `line_width` em `/line/detection` deve bater com a largura
   real da fita quando o robô está bem posicionado — é o teste da própria
   calibração.

---

## Histórico de correções relevantes

Para contexto de quem for revisar o código ou continuar os testes —
achados que só apareceram com o robô físico rodando, não visíveis em
revisão estática:

- **Matriz mecanum**: corrigida para X convencional depois da troca das
  rodas (roletes deixaram de estar espelhados nas traseiras). Verificado
  algebricamente (`INV @ F == identidade`) e com giro puro dando
  velocidades simétricas nas quatro rodas.
- **`k_feedforward` alto (0.85) cancelava a correção primária** — a
  curvatura da câmera inferior, com baseline de só ~10 cm, é ruidosa
  demais para um feedforward forte. Reduzido para 0.15 com validação ao
  vivo (erro lateral contido em ±2mm vs. deriva de 13-18mm antes).
- **Quina real (não curva suave) faz a curvatura ajustada explodir**
  (chegou a +11 1/m numa dobra de ~30°) — resolvido com
  `preview_heading_gain` (usa o ângulo direto da câmera superior, que não
  sofre da mesma instabilidade) e o guard `max_heading_for_curvature`.
- **Desalinhamento do próprio robô também inflava a curvatura** mesmo em
  pista reta (23° de desvio → +7 a +10 1/m medido) — mesmo guard resolve.
- **Servo físico invertido**: comando de `+25°` girava para a esquerda.
  Corrigido isolando a inversão na fronteira ROS↔serial
  (`motor_serial_node`), nos dois sentidos (`/servo/command` de saída e
  `SERVO_STATE` de entrada), para que o resto do sistema nunca precise
  saber disso.
- **`serial_read_rate` a 200 Hz** consumia ~40% de uma CPU do Pi só de
  polling, derrubando o FPS das câmeras por contenção — reduzido para
  50 Hz (10x a taxa real de chegada de telemetria do firmware, que é
  200 ms).
- **`head_servo_node` sem `add_on_set_parameters_callback`**: ajustes via
  `ros2 param set` não tinham efeito nenhum até reiniciar o nó — corrigido
  adicionando o callback (exceto `rate_hz`, que recria o timer e por isso
  continua exigindo restart).

### Sessão de 09/09/2026 — câmera superior, curva e alinhamento

Todas as afirmações abaixo vêm de corridas instrumentadas com o robô
andando, não de estimativa.

- **A câmera superior estava desestabilizando a direção.** Teste A/B
  isolado: com a realimentação do ângulo da cabeça no giro do corpo, o
  robô perdia a linha 31–33% do tempo e o viés de curva chegava a
  −16 mm. Deixando a cabeça **livre para rastrear** mas **sem
  realimentar** (`head_tracking_enabled: true`, `use_servo_bearing:
  false`), fez 45 s contínuos sem perder a linha uma vez e o viés caiu
  para +0,46 mm. A cabeça se mover não é o problema — injetar a leitura
  dela no laço fechado é.
- **Uma flag conflava quatro papéis.** `use_preview` controlava direção,
  realimentação do servo, velocidade **e recuperação** de uma vez.
  Desligá-la para curar a direção matava silenciosamente a dica de
  recuperação. Agora cada papel tem a sua chave (`preview_*_enabled`).
- **`use_servo_bearing` congelava a cabeça junto.** Desligar a
  realimentação mandava `head_mode` para `CENTER`, misturando duas
  decisões numa flag só — um A/B que queria isolar a realimentação
  acabava mudando duas variáveis. Separado em `head_tracking_enabled`.
- **A recuperação pela superior quase nunca está disponível.** Medido:
  quando a inferior perde a linha, a superior perdeu junto — confiança
  0,015 e utilizável em 0,3% dos frames perdidos. O FOV dela (±16,4°) é
  estreito demais para servir de sensor de recuperação. Foi mantida
  ligada porque é barata e segura, mas **não conte com ela**.
- **Em curva a curvatura é geometricamente indisponível.** Ela exige 4
  das 5 bandas, e as bandas distantes saem do quadro justamente quando o
  heading cresce: a 13,5 cm com heading de 20° a linha está a
  `20,6 + 135·tan20° = 69 mm`, além dos ±64 mm que aquela banda cobre.
  Medido: 71% da invalidez de curvatura vem de bandas insuficientes.
- **O `atan()` da antecipação da cabeça satura fácil.** `bearing =
  atan(D·κ/2)·ganho` com ganho 0,8 levava a cabeça a 44,7° (batente 45°)
  com curvatura de só 7,9 1/m. Reduzido para 0,5.
- **`/servo/state` é eco, não medição.** O firmware guarda o valor
  recebido e devolve ([`main.cpp:249`, `:208`]); servo de hobby não tem
  realimentação de posição. Para provar que a cabeça girou, compare
  imagens da câmera, não esse tópico.
- **Duas stacks rodando ao mesmo tempo** (uma minha, uma manual)
  produziram leituras de parâmetro misturadas e disputa de tópicos. O
  sintoma é `ros2 param list` vindo **duplicado**. Confira sempre
  `pgrep -af line_follower_node` antes de confiar numa medição.

### Sessão de 10/09/2026 — o reflexo da câmera inferior

**Sintoma relatado:** "camera inferior pega reflexo luminoso na parte
superior, uma das bandas fica quebrada."

**Medido no quadro capturado.** A mediana do piso cai de **151 (longe)
para 106 (perto)** — 45 contagens — mais 19 de inclinação lateral,
contra apenas **78** de contraste entre a linha e o piso. Ou seja, o
gradiente de iluminação valia mais da metade do sinal.

O Otsu que cada banda pediria ia de 168 (longe) a 131 (perto); o global
saiu **155**. Na banda distante o piso ao lado da fita estava em 151 —
4 contagens abaixo do limiar — e se **fundia** com ela:

```
banda 0   seg x  34..110  (39.9 mm)   <== o dobro da largura real
banda 1   seg x  55.. 94  (20.5 mm)
banda 2   seg x  56.. 94  (19.9 mm)
banda 3   seg x  56.. 94  (19.9 mm)
banda 4   seg x  56.. 94  (19.9 mm)
```

Com `line_width_tolerance: 0.45`, uma banda de 39.9 mm no lugar de 20 mm
é rejeitada pelo termo de largura. Daí "uma das bandas fica quebrada".

**Por que isso era o gargalo.** Na corrida anterior `1 - confiança` era o
**maior** termo do freio de velocidade (0.54 médio, p90 0.94) — o robô
andava devagar porque a detecção não confiava em si mesma, não por
geometria. E `1 - obs.confidence` entra direto em `_severity()`.

**Correção:** achatamento de fundo por *top-hat* com kernel horizontal,
antes do limiar. Para cada linha da imagem o fundo é o mínimo local numa
janela mais larga que a fita; subtraí-lo remove qualquer iluminação
suave. O limiar passa a sair da imagem achatada, mas **o contraste e o
teste de flanco continuam lendo o `gray` original** — eles medem física
da cena (linha branca ladeada de fita preta), não artefato de limiar.

Medido ao vivo, mesma posição, antes → depois:

| | antes | depois |
|---|---|---|
| bandas | 4/5 | **5.00/5** (mínimo 5) |
| confiança | 0.757 | **0.872** |
| contraste | 78.0 | 81.2 |
| largura | 19.9 mm | 19.9 mm |
| erro lateral | −2.6 mm | −2.6 mm |
| heading | −0.44° | 0.00° |

Largura e erro lateral **não mudaram** — a correção não introduziu viés,
só devolveu a banda. O heading limpou porque a banda inchada torcia o
ajuste.

**Custo de CPU: +0.26 ms sobre 6.71** (4%), medido intercalado. A
primeira medição deu +18 ms e estava **errada**: as duas metades do A/B
rodaram em instantes diferentes com a pilha inteira competindo por CPU.
Intercalar A/B/A/B cancela a deriva de carga — vale para qualquer
medição de desempenho neste Pi.

**Por que o kernel é 3× a largura da linha.** A janela precisa superar a
linha mais larga que a varredura horizontal pode ver: uma linha inclinada
em θ mede `largura/cos(θ)`, o **dobro** a 60°. Janela estreita demais faz
o top-hat comer a linha justamente na curva. Coberto por
`test_achatamento_nao_come_a_linha_inclinada`.

**Desligado na câmera superior**, e isso foi medido, não presumido: lá o
Otsu local de cada banda deu 169/173/172/170/171 contra 171 do global —
não há gradiente em profundidade. Ligar custaria: a largura medida caiu
de 19.3 para 18.0 mm, porque essa câmera tem perspectiva e uma janela
única é sempre um compromisso. **Reconsiderar** se voltar a sombra
diagonal que já prendeu a confiança dela em 0.49–0.52 com contraste 74:
contraste alto com confiança baixa é exatamente esta assinatura.

### Sessão de 10/09/2026 — o limite de quebra é 66°, e agora está medido

Com a câmera superior religada em **velocidade e recuperação** (direção
ainda desligada) e o `corrida.py` gravando **as duas câmeras**, a corrida
de 45 s atravessou 7 quebras. A superior avisou 4 delas, com 1.55 a
3.38 s de antecedência.

| quebra medida | desvio geométrico | cabe na margem? | parou? |
|---|---|---|---|
| 66.3° | 32.1 mm | **NÃO** | 1.44 s |
| 51.8° | 18.4 mm | sim | 0.00 s |
| 37.2° | 9.1 mm | sim | 0.00 s |
| 34.9° | 8.0 mm | sim | 0.00 s |

O desvio é `R(1/cos(Δ/2) − 1)` com `R = wheel_base_k / arc_ratio =
0.165 / 1.00 = 165 mm`, contra a margem de **31.9 mm** (campo de 83.9 mm
menos a fita de 20, dividido por dois).

Resolvendo para a margem atual: **o limite é 66.1°**. A única quebra que
travou mediu **66.3°** — 0.2° acima. As três que cabiam passaram sem
parar nenhuma vez.

**Ressalva de honestidade:** são 4 quebras, e o pico de heading é um
*proxy* do ângulo da quebra, não uma medida direta dele. A concordância
de 0.2° tem sorte dentro. O que é sólido é a **ordenação**: toda quebra
abaixo do limite passou, a única acima travou.

**O que a superior faz e o que ela não faz.** Ela avisou 2.21 s antes da
quebra de 66.3° — e o robô travou assim mesmo. Aviso não conserta
geometria: se o arco mínimo não cabe no campo, antecipar só faz frear
mais cedo. Onde ela paga é nas quebras que *cabem*: as de 51.8°, 37.2° e
34.9° passaram em arco, sem parada, e na corrida só com a inferior a
quebra grande equivalente parava 0.6 s.

**Como subir o limite** (em ordem de custo):

1. **Levantar a câmera inferior de 87 para ~110 mm.** O campo escala 1:1
   com a altura nesta lente, então a margem vai de 31.9 para 45 mm e o
   limite de quebra sobe de 66° para **76.4°**. Só remontagem e
   recalibração — nenhuma linha de código.
2. **Suavizar as quebras da pista**, que já era o seu plano.
3. `arc_ratio` acima de 1.0 diminuiria `R`, mas 1.0 já é o limite de
   tração: acima disso o robô pirueta em vez de arquear.

**Métricas da corrida** (melhores de todas até aqui): 99.8% de quadros
válidos, `|lat|` p50 **10.0 mm**, viés **+0.30 mm**, 3 perdas somando
**0.08 s**, 4.72 m percorridos, entrega 88%.

**Limite da própria superior:** válida em 86% dos quadros, curvatura
válida em 80%. Quando ela perde, o freio antecipado sai do ar sem aviso.

### Sessão de 10/09/2026 — 3 min de dados, e duas hipóteses minhas mortas

Corrida de 180 s, 22.088 amostras, **21.1 m**, gravada em
`logs/corrida_20260910_193825.csv`.

```
válidas 99.77%   |lat| p50 8.4  p90 26.5  max 35.4 mm   viés +1.10
perdas  4 episódios, 0.41s total (0.23% do tempo), maior 0.16s
entrega 93%      conf 0.674   bandas 4.66
19 quebras, 2 travadas (62.9° e 65.6°); tudo até 53.0° passou em arco
bateria 11.90 -> 11.91 V (mín 11.85) — sem queda em 3 min
```

**O limite de quebra precisa descontar o erro de rastreio.** O desvio da
quebra SOMA com o desvio que já existe: o robô não chega centrado, chega
com os ~8.4 mm típicos. Corrigindo o modelo:

| | só geometria | com o rastreio real |
|---|---|---|
| hoje (87 mm) | 66.1° | **57.8°** |
| com 110 mm | 76.4° | **70.1°** |

O modelo corrigido cai entre 53.0° (passou) e 62.9° (travou). O anterior
previa 66.1° e teria dito que as duas travadas deveriam passar.

#### Duas hipóteses de ajuste que a medição matou

Valem documentadas porque são erros plausíveis de repetir.

**1. "wz serrilha na reta, `k_lateral` está alto."** Falso. A
autocorrelação do `wz` na reta decai de +0.975 (40 ms) a +0.004 (960 ms)
**sem lóbulo negativo** — não há oscilação nenhuma, é um sinal suave com
~1 s de tempo de correlação. As 2.4 reversões de sinal por segundo são
travessias naturais de um sinal que ronda o zero. E 100% delas ocorrem
com o erro lateral do mesmo lado: é o termo de heading recuando na
aproximação, ou seja, o amortecimento fazendo o trabalho dele.

**2. "solavanco de vx, p99 de 1.485 m/s²."** Artefato de medição. O CSV
amostra a ~123 Hz e o controle roda a 50 Hz, então linhas consecutivas
têm dt ~7 ms com um passo inteiro de controle entre elas, e a divisão
infla a taxa. **Reamostrando na taxa real de controle: p99 0.857, máx
1.065** — as rampas configuradas (`accel: 0.35`, `decel: 0.60`) mais o
jitter de dt. Já existe limite de taxa e ele está funcionando.

> Lição geral: taxa derivada de um log só vale se o log e o laço tiverem
> a mesma taxa. Reamostre antes de derivar.

#### O que sobrou de real: a superior fica cega na quebra

Ela está inválida em **13.8% dos quadros** (24.7 s de 180), em 37
episódios. Seis episódios longos concentram **17.0 s**, e **5 desses 6
são seguidos de uma quebra em até 3 s**.

Não é o servo — a validade é melhor com a cabeça virada (94.9% entre
+8° e +20°) do que centrada (85.0%). Ela degrada antes de cair:
no quadro da queda a confiança já vinha em 0.166 com 2.08 bandas.

Ou seja, **o preview apaga exatamente quando mais vale**. É geometria do
campo dela (20.5 a 54.5 cm à frente): na quebra a linha sai do campo
distante. Próximo alvo de investigação — ROI e parâmetros da superior,
não ganhos do controlador.

### Sessão de 10/09/2026 — duas armadilhas do apontamento da cabeça

#### 1. `/head/request` tem DOIS publicadores

`line_follower_node` publica `/head/request` a 50 Hz sempre que a
autonomia está ligada. Qualquer script que também publique **disputa o
servo com ele**, e o resultado é o servo sendo puxado para o alvo do
seguidor no meio do movimento pedido.

Custou uma conclusão de hardware **errada** nesta sessão. Um teste de pan
sem o handshake deu:

```
-35° vs   0° :  2.31 níveis de cinza     <== "a câmera não gira"
  0° vs +35° :  2.32
-35° vs +35° :  2.33
```

Reportei que o servo tinha soltado do suporte. O sintoma que desmentiu
isso veio do operador: *"vejo ele se mexendo sim, mas parece que tem
algo puxando ele pro centro ao mesmo tempo"* — assinatura exata de dois
publicadores. Com `head_control_enabled: false` calando o seguidor, o
MESMO teste no MESMO hardware:

```
-35° vs   0° : 55.94 níveis de cinza     <== gira perfeitamente
  0° vs +35° : 26.36
-35° vs +35° : 49.57
```

**Sempre cale o seguidor antes de comandar a cabeça:**

```bash
ros2 param set /line_follower_node head_control_enabled false
# ... seu teste ...
ros2 param set /line_follower_node head_control_enabled true
```

`logs/servo_prova.py` e `logs/varredura.py` já fazem isso sozinhos.

#### 2. `/servo/state` é eco, não posição

`SERVO_STATE` no firmware (`main.cpp` linha 208) espelha `servoAngle`
(linha 249). Ou seja, **nenhuma checagem por tópico distingue "servo
girou" de "servo recebeu o comando e não girou"** — durante o teste
contaminado acima, `/servo/state` reportava +16.1° com toda a
convicção enquanto a imagem não mudava.

A prova é sempre a IMAGEM: capture em ângulos opostos e compare. Um pan
de 70° numa lente de ~53° desloca a cena por mais de uma largura de
quadro; abaixo de ~3 níveis de cinza é ruído de sensor.

#### 3. Comparar medições exige a MESMA cena

Duas medições da superior na "mesma" posição deram 287/287 quadros
válidos e 0/14. Não era ruído nem bug: o robô tinha sido movido entre
elas enquanto o suporte era inspecionado. Registre o `heading` da
inferior junto de qualquer leitura da superior — foi ele que denunciou
a troca de cena (+24° na quebra contra ~0° na reta).

### Sessão de 10/09/2026 — fechamento: a mira da cabeça, medida

Corrida de 180 s com a mira nova (`_mira_da_cabeca` + `track_hold_tau`),
em `logs/corrida_20260910_203230.csv`. Bateria 11.47 -> 11.42 V
(mín 11.41) — ficou acima do limiar, não contaminou.

#### O ganho está na disponibilidade da superior

| | antes | agora |
|---|---|---|
| superior válida | 86.0% | **94.9%** |
| tempo cega | 24.7 s | **9.0 s** |
| maior apagão | 5.70 s | **2.13 s** |
| quedas | 37 | 32 |
| `\|servo\|` médio | 4.4° | **8.6°** (máx 45°) |

E a validade cresce monotonicamente com o quanto a cabeça aponta —
o mecanismo confirmado de dentro dos dados:

```
servo  -8..+8   n=15239   válida 94.7%
servo  +8..+20  n= 3555   válida 96.4%
servo +20..+45  n= 2631   válida 97.3%
```

Antes desta mudança a mira comandava **0.0° em qualquer situação**: ela
vinha da curvatura da inferior, que fora desligada com evidência.

#### O limite geométrico: 6 de 6 entre duas corridas

Esta corrida caiu numa distribuição de quebras mais dura (p90 55.0 ->
60.2°, máx 65.6 -> 71.8°). Separando pelo limite de 57.8°:

| | corrida anterior | corrida de fechamento |
|---|---|---|
| quebras acima de 57.8° | 2 | 4 |
| delas travaram | **2/2** | **4/4** |
| abaixo de 57.8°, travaram | 0/17 | 2/19 |
| **parada média por travada** | 1.91 s | **0.76 s** |

Toda quebra acima do limite travou, nas duas corridas. O modelo
`R(1/cos(Δ/2) − 1) + erro de rastreio ≤ margem` está validado com n=6.
O que a mira melhorou não foi *evitar* a travada — geometria não se
negocia — e sim **sair dela 60% mais rápido**.

#### Resumo do corpo (praticamente inalterado, como esperado)

```
válidas 99.6%   |lat| p50 9.2  p90 26.0 mm   viés -0.91
perdas  4 episódios, 0.69 s        entrega 92%
20.2 m em 3 min, com quebras mais fechadas que na corrida anterior
```

#### Pendências para a semana que vem

1. **A superior não vê a linha no vértice** — e isso não é ajuste de
   detector: no vértice a pista já saiu do campo dela (20.5 a 54.5 cm à
   frente). Ela é sensor de AVISO (17/23 quebras, 1.5 a 3.4 s de
   antecedência), não de reencontro. Planejar em cima disso.
2. **Levantar a inferior para ~110 mm** sobe o limite de 57.8° para
   70.1°, cobrindo as quatro quebras que travaram nesta corrida.
   Decisão do operador foi adiar; a quebra fechada vira o teste.
3. **Suavizar as quebras da pista** — as acima de 63° são
   fisicamente impossíveis para este chassi na margem atual.

### Sessão de 10/09/2026 — "a guiada ficou mais ruidosa": o que a medição disse

Relato do operador após 2 voltas: *"o servo tá se alinhando bem com o
futuro da pista e curvas, mas a guiada em si achei um pouco mais ruidosa
do que naquele teste perfeito, mas ainda boa."*

**O comando não ficou mais ruidoso.** Comparando as duas corridas de
3 min, reamostradas a 50 Hz e restritas a reta em movimento:

| | corrida anterior | fechamento |
|---|---|---|
| `\|dwz/dt\|` p99 | 4.053 | **3.560** |
| `\|dvx/dt\|` p99 | 0.801 | **0.682** |
| erro de seguimento vx | 0.0289 | **0.0265** |
| erro de seguimento wz | 0.1542 | **0.1493** |
| escorregamento `\|vy\|` | 0.0093 | **0.0083** |
| bateria média | 11.88 V | 11.44 V |

Tudo igual ou melhor, com bateria pior. E a cabeça não contamina a
direção: correlação de **+0.044** entre `|dservo/dt|` e `|dwz/dt|`.

**O que o operador viu:** três vezes mais hesitações. A corrida caiu numa
distribuição de quebras mais dura (máx 65.6° -> 71.8°) e travou **6 vezes
contra 2** — cada travada 60% mais curta, mas o triplo delas. Some a isso
a cabeça se mexendo **2.5× mais** (5.48 -> 13.68 °/s).

#### Dois alarmes falsos evitados no caminho

Registrados porque o reflexo de acusar hardware é forte e estava errado
nas duas vezes:

**1. "As rodas da direita entregam só 82% das da esquerda."** Falso. A
pista é um **circuito fechado**: a odometria acumulou −12.5 e −11.1 rad,
ou seja 1.98 e 1.77 voltas. Pela cinemática mecanum, `dir − esq =
2·K·wz_médio`. Previsto −0.0238 e −0.0217 m/s; medido −0.0238 e −0.0217.
**Resto inexplicado: 0.0000.** Sempre desconte o giro líquido antes de
comparar lados.

**2. "21% dos quadros têm roda parada com comando alto."** Também falso
como enunciado: numa curva `FL = vx − K·wz` fica perto de zero sem falha
nenhuma. Filtrando pela previsão cinemática, sobram 14.6% — e ESSES são
reais (ver checklist da próxima sessão).

### Sessão de 18/09/2026 — firmware 2.0

Reescrita das fundações do firmware. Tudo medido antes e depois; os
números abaixo saem de `logs/` e do `DIAG` da propria telemetria.

| | antes | depois |
|---|---|---|
| quantizacao da velocidade de roda | 0.0743 m/s | **0.0186** (x4) |
| idem, na telemetria (janela 100 ms) | 0.0743 m/s | **~0.002** |
| `/odom` | 5 Hz | **50 Hz** |
| baud / ocupacao do link | 115200 / 9.1% | **921600 / 4.7%** |
| eixo do yaw da IMU | `gz` (morto) | `gx`, detectado pela gravidade |
| atrasos do laco de controle | 2.07% | **0.00%** |
| linhas seriais malformadas | 2 em 3283 | **0 em 4699** |

#### O que cada coisa consertou

**Encoders x1 -> x4.** Com x1 e janela de 10 ms a velocidade de roda so
podia valer multiplos de 0.0743 m/s, e o robo anda entre 0.07 e 0.20.
Uma roda a 0.106 m/s da 1.43 ticks por janela; abaixo de 1 ela le
EXATAMENTE ZERO girando perfeitamente. **Era isso, e nao falha
mecanica, que produzia o "roda parada" nos diagnosticos de pista** --
o achado que estava no topo do checklist da semana anterior e que agora
esta explicado e riscado.

**Migracao de Settings.** O NVS so tinha um flag "ok" ("ja gravei
alguma vez"), sem versao: mudar um default nunca chegava a um robo com
NVS gravada. Agora ha `SETTINGS_VERSION` com migracao -- a v1->v2
multiplica `ticksRev` por 4 em vez de forcar o default, preservando
calibracao fina.

**IMU no eixo errado.** A placa esta em pe, com o chip apontando para a
frente. Medido com o robo parado: a gravidade aparece em `ax = +9.85`,
nao em `az`. O firmware lia `gz`, que nesse arranjo e horizontal e fica
em ~0.001 rad/s -- o yaw integrado andava a 15% da taxa real, e o
`calibrate()` removia vies de `gz` enquanto `gx` carregava -0.132 rad/s
sem correcao. Nao afetou o controle (o ROS le `twist.angular.z`, que
vinha so dos encoders), mas deixava a IMU inutil.

**IMU agora entra no controle.** `od.wz` passou a ser 85% giroscopio +
15% encoder. Num mecanum os roletes patinam por projeto, entao a wz dos
encoders SUPERESTIMA rotacao justamente na curva. Verificado antes de
ligar: ruido 0.032 graus/s, vies sem deriva (-0.13169 -> -0.13170 em
60 s), e o SINAL conferido girando o robo a mao para a direita (97 de 97
amostras negativas, como manda a REP-103). Novo topico `/wheel_slip` =
wz_encoder - wz_giroscopio: patinagem medida, nao inferida.

**Tela apagada durante o movimento.** `display.display()` empurra 1024
bytes por I2C a 400 kHz -- ~23 ms bloqueando o mesmo `loop()` que roda o
controle a 100 Hz. Ideia do operador, e ela venceu a minha proposta de
task dedicada no core 1: periodo maximo caiu de 29843 para 13611 us e os
atrasos de 2.07% para **zero**, sem nenhum risco de concorrencia. A
task separada foi **descartada por medicao**, nao implementada.

> Armadilha: a condicao inicial era `!ros`, e estava errada. O
> `motor_serial_node` publica TWIST a 50 Hz mesmo com o robo PARADO,
> entao a tela nunca mais acendia com a pilha no ar. O criterio certo e
> movimento comandado, com histerese de 1 s.

**CRC8 nos comandos, so no sentido Pi -> ESP32.** Telemetria corrompida
o parser ja descarta pelo cabecalho; comando corrompido vira velocidade
errada num robo que anda. Testado: sem CRC passa (compatibilidade), com
CRC certo passa, com CRC errado e recusado e contado. A telemetria segue
em texto puro, entao `cat /dev/ttyACM0` continua servindo.

**UI do OLED.** Barra superior fixa com icones (bateria com nivel e
piscando quando critica, link serial, IMU), STATUS com tensao grande e
barras bipolares de VX/WZ, listas com selecao invertida e barra de
rolagem, telas HOST (IP da Raspberry, via `SET_INFO`) e DIAG (jitter,
CRC recusado, motivo da parada, uptime). Menu abre no clique e volta
para STATUS apos 10 s sem toque.

> Armadilha: o `clearDisplay()` estava espalhado por cada funcao de
> desenho e o STATUS ficou sem -- ele desenhava POR CIMA do menu
> anterior. Agora e **um so**, no inicio de `draw()`, onde e impossivel
> uma tela nova nascer sem ele.

#### Ferramenta nova: `gravar.sh`

Grava o firmware derrubando a pilha ROS antes e subindo depois. Existe
porque o `motor_serial_node` segura `/dev/ttyACM0` e o upload falha com
erro confuso (o esptool reclama de sincronismo, nao de porta ocupada).

> Armadilha: a primeira versao matava so `robot_bringup/`, mas o
> `camera_node` vem do pacote `camera_ros` e sobrevivia segurando o
> pipeline do libcamera. Chegaram a rodar **tres instancias empilhadas**.
> O script agora casa a arvore inteira do launch e ABORTA se sobrar
> processo, em vez de empilhar.

### Sessão de 18/09/2026 — a câmera está perfeita; a percepção e que perde quadro

Investigacao aberta pelo operador: *"no rqt eu vejo mais frames do que
18"*. Ele estava certo, e a correcao derrubou uma conclusao minha.

**A camera entrega 30 Hz exatos, sem jitter.** Medido contando
`camera_info` (mensagem minuscula) em vez de `image_raw` (1 MB/quadro):

```
901 quadros em 30 s = 30.0 Hz, nas duas cameras
carimbo de captura do driver:  p50 33.30   p90 33.31   max 33.35 ms
FrameDurationLimits = [33333, 33333] us  -> 30 fps travados
```

**RETRATADO:** eu havia reportado a camera com `p90 98 ms` e picos de
`503 ms`. Era **o meu proprio no de medicao engasgando** ao receber
imagens de 1 MB em Python -- medi o meu gargalo e atribui a camera.

> Licao: para medir a CADENCIA de um topico de imagem, conte um topico
> leve publicado junto (`camera_info`) ou o carimbo do driver. Um
> assinante Python de `image_raw` mede a si mesmo.

**O que de fato perde quadro e a percepcao**: recebe 16-28 dos 30,
processando em 5.5-11 ms. Como processar leva ~9 ms e ainda assim ela
perde, o custo esta em RECEBER e converter, nao em processar.

#### Vale reescrever visao e controle em C++?

| | medido | veredito |
|---|---|---|
| CPU da pilha ROS | 181% de 400% | nao ha escassez |
| jitter do controle (alvo 20 ms) | p50 19.8, p99 26.2, zero estouros | **C++ nao ajuda** |
| quadros perdidos na percepcao | ~25% | **so aqui C++ ajudaria** |

O grosso do processamento ja E C++: `resize`, Otsu, morfologia e top-hat
sao OpenCV compilado. O Python so orquestra. C++ atacaria o custo de
RECEBER a imagem -- e seria reescrever a parte mais sutil e mais testada
do projeto (160 testes na geometria) por ~35% de um nucleo que sobra.

#### Caminho barato ainda ABERTO: resolucao

O detector reduz para `work_width` (160 px) na PRIMEIRA operacao: de
307200 px ele usa ~19200. Os outros 16x sao serializados, transportados
e convertidos para serem jogados fora.

A 320x240 a CPU caiu forte -- percepcao 68.5% -> 45.8%, camera 38.0% ->
20.5%. Isso e solido (CPU nao depende da cena).

**Mas falta provar que o campo de visao e PRESERVADO.** Se o libcamera
escolher um modo que CORTA em vez de escalar, a margem lateral encolhe
-- e margem e exatamente o que limita a quebra (57.8 graus). Perder
campo por CPU que sobra seria pessimo negocio.

A primeira tentativa de medir isso **nao vale**: usei a largura
reportada da fita como sonda, e o robo nao estava sobre a linha (imagem
crua escura e desfocada, confianca 0.11). As leituras de 20.73, 28.62 e
38.16 mm foram todas sobre cena invalida.

Para fechar, com o robo NA PISTA:

```bash
python3 logs/fov.py 640x480          # com a pilha em 640x480
# relancar com cam_width:=320 cam_height:=240
python3 logs/fov.py 320x240
```

`logs/fov.py` mede a **fracao da largura do quadro** ocupada pela fita,
sem depender do detector nem da calibracao. Fracao igual = so escala, e
320x240 sai de graca. Fracao maior = esta cortando, e a ideia morre.

#### Ponta solta fechada

O modo parecia voltar sozinho de SEGUIDOR para PARADO. Testado: 3 min
observando `/robot/mode`, **zero mudancas espontaneas**. Era script meu
publicando PARADO sem eu rastrear. Nao ha bug.

> E de novo a armadilha do DDS: publicar em `/robot/mode_request` sem
> esperar `get_subscription_count() > 0` faz o pedido cair no vazio.
> `logs/modo.py` ja espera a descoberta -- use ele.

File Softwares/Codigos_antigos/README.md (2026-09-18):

# Código antigo

Versões anteriores do software, guardadas como registro da evolução do
projeto. **Nada aqui é usado pelo robô atual** — servem para consulta
histórica.

| pasta | o que era | substituído por |
|---|---|---|
| `IC_seguidor_S3/` | primeiro firmware do ESP32-S3 | `Softwares/Firmware_Ippo/` |
| `Firmware_Ippo.zip` | firmware empacotado em zip | `Softwares/Firmware_Ippo/` (agora versionado como fonte) |
| `line_control/` | nó de controle da primeira arquitetura | `robot_bringup/line_controller.py` + `line_follower_node.py` |
| `line_vision/` | nó de visão da primeira arquitetura | `robot_bringup/line_geometry.py` + `line_perception_node.py` |

## O que mudou da arquitetura antiga para a atual

A primeira versão tinha um nó de visão e um de controle conversando por
tópico, com a lógica misturada ao ROS. A atual separa a **geometria pura**
(`line_geometry.py`, `line_controller.py` — sem ROS, testáveis com
`pytest`) dos **nós** que só fazem a ponte com o ROS. São 160 testes
automatizados em cima dessa parte pura.

Do lado do ESP32, o firmware passou de um laço único para módulos
(`MotorDriver`, `EncoderManager`, `ImuManager`, `LocalMenu`,
`SerialProtocol`, `Settings`), com telemetria em dois grupos de taxa,
CRC nos comandos e menu de modo no OLED.

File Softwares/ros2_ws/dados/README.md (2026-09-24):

# Dados de corrida

Saída do `scripts/corrida.py`: percepção das duas câmeras, comando,
atuação (`/odom`, `/wheel_states`) e bateria, amostrados juntos.

| arquivo | o que é |
|---|---|
| `corrida_20260910_193825.csv` | 3 min, só a inferior nos papéis de direção |
| `corrida_20260910_203230.csv` | 3 min, fechamento, com a mira nova da cabeça |

| `corrida_20260924_112344.csv` | 45 s, antes da memória de freio: freio do preview soltava 12-16 cm antes da quina, 2 perdas em 5 |
| `corrida_20260924_120518.csv` | 3 min, memória de freio (renovada também pela curvatura): 74% do tempo segurando, vx 0,087, 1º mapa fechado (1,5 cm) |
| `corrida_20260924_130437.csv` | 3 min, perfil SUAVE (antes de existir o perfil), trim do servo no firmware |
| `corrida_20260924_132102.csv` | 3 min, MÉDIA; mostra a curvatura-ruído da superior prendendo o robô em v_min nas retas |
| `corrida_20260924_132830.csv` | 3 min, MÉDIA com a memória só pelo heading: vx 0,124, volta 76 s |
| `corrida_20260924_133532.csv` | 3 min, RÁPIDA (0,12/0,44): vx 0,168, volta 58 s, 8 recuperações < 0,8 s |

As de 24/09 gravam **uma linha por quadro da câmera inferior** (~21-27 Hz)
e têm `x_m`, `y_m`, `yaw_deg` (pose do firmware, para `tools/mapa.py`) e,
a partir de 13:21, `perfil` (0 SUAVE, 1 MÉDIA, 2 RÁPIDA).

São estas duas que sustentam o **limite de quebra de 57,8°** citado no
README: toda quebra acima dele travou nas duas corridas (n=6), e nenhuma
abaixo travou na primeira.

**Ao derivar taxas destes CSVs, reamostre a 20 ms primeiro.** O arquivo
grava a ~123 Hz e o controle roda a 50 Hz; derivar linha a linha infla a
aceleração — deu 1.485 m/s² onde o valor real era 0.857.

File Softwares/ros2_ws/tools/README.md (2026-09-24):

# logs/ — dados e ferramentas de bancada

## Corridas gravadas

`corrida_AAAAMMDD_HHMMSS.csv` — saída de `scripts/corrida.py`. Grava
percepção das DUAS câmeras, comando, atuação (`/odom`, `/wheel_states`)
e bateria. Nome com timestamp de propósito: comparar duas configurações
exige as duas corridas, e um caminho fixo já sobrescreveu uma delas.

| arquivo | o que é |
|---|---|
| `corrida_20260910_193825.csv` | 3 min, só a inferior nos papéis de direção |
| `corrida_20260910_203230.csv` | 3 min, fechamento, com a mira nova da cabeça |
| `corrida_com_superior.csv` | 45 s, primeira com a superior religada |
| `corrida_instrumentada.csv` | 45 s, primeira com as duas câmeras gravadas |

**Ao derivar taxas destes CSVs, reamostre a 20 ms primeiro.** O arquivo
grava a ~123 Hz e o controle roda a 50 Hz; derivar linha a linha infla a
aceleração (deu 1.485 m/s² onde o valor real era 0.857).

## Ferramentas

| script | para quê |
|---|---|
| `amostra.py` | leitura rápida das duas câmeras, parado. Sem mover nada. |
| `captura.py` | salva imagens cruas e de debug das duas câmeras em `~/quebra/` |
| `quebra_teste.py` | **antes/depois da mira da cabeça num disparo só** — detecções, servo e imagens no MESMO instante |
| `servo_prova.py` | prova que o servo gira a câmera, comparando quadros em ±35° |
| `varredura.py` | varre o servo por N segundos para inspeção visual do eixo |

`servo_prova.py` e `varredura.py` calam o seguidor
(`head_control_enabled: false`) e devolvem a autoridade no fim. **Todo
script que comande a cabeça precisa fazer isso** — `line_follower_node`
publica `/head/request` a 50 Hz e disputa o servo, o que já produziu um
diagnóstico de hardware falso.
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

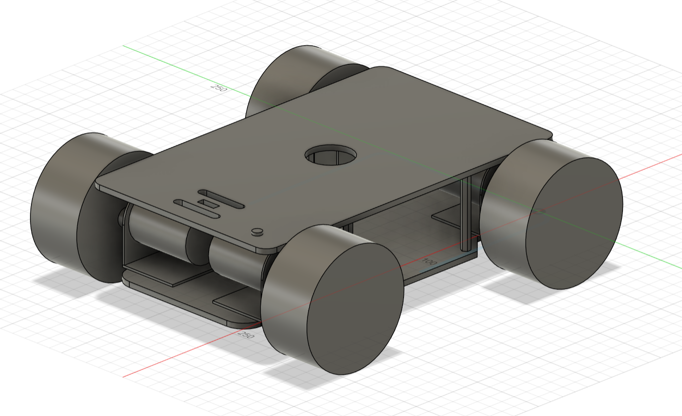
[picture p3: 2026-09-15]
Mecanica/Base Mecanum/image.png

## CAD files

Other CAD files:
Mecanica/Base Mecanum/chassi migo base.f3d

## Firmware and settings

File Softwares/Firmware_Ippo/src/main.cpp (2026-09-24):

#include <Arduino.h>
#include <Wire.h>
#include <ESP32Servo.h>
#include "Config.h"
#include "RobotTypes.h"
#include "Settings.h"
#include "MotorDriver.h"
#include "EncoderManager.h"
#include "WheelPid.h"
#include "ImuManager.h"
#include "BatteryMonitor.h"
#include "Feedback.h"
#include "LocalMenu.h"
#include "SerialProtocol.h"

MotorDriver motor;
EncoderManager enc;
ImuManager imu;
BatteryMonitor batt;
Feedback fb;
LocalMenu menu;
SerialProtocol serial;
Settings cfg;
Servo servo;
WheelPid pid[Config::N];

// Versao do firmware e do protocolo serial. Subir PROTOCOL_VERSION
// sempre que o formato das linhas mudar de forma incompativel.
constexpr char FIRMWARE_VERSION[] = "2.0.0";
constexpr uint8_t PROTOCOL_VERSION = 2;
WheelState ws;
Odom od;
Twist cmd;
float appliedYaw = 0.0f;
uint32_t lastControl = 0;
uint32_t lastCmd = 0;
uint32_t lastTel = 0;
uint32_t lastTelFast = 0;
uint32_t stallSince[Config::N] = {};
uint32_t lastMoving = 0;

// INSTRUMENTACAO DO LACO DE CONTROLE.
//
// O controle quer rodar a cada 10 ms, mas roda "quando o loop() chegar
// la". Sem medir isso nao da para saber se vale mover o controle para
// uma task propria -- e complexidade de concorrencia so se paga com
// numero na mao. Publicado em DIAG e zerado a cada relatorio.
struct CtlStats {
  uint32_t periodoMin = 0xFFFFFFFF;
  uint32_t periodoMax = 0;
  uint64_t periodoSoma = 0;
  uint32_t execMax = 0;
  uint32_t amostras = 0;
  uint32_t atrasos = 0;      // periodos acima de 15 ms

  void registra(uint32_t periodoUs, uint32_t execUs) {
    if (periodoUs < periodoMin) periodoMin = periodoUs;
    if (periodoUs > periodoMax) periodoMax = periodoUs;
    if (execUs > execMax) execMax = execUs;
    periodoSoma += periodoUs;
    amostras++;
    if (periodoUs > 15000) atrasos++;
  }

  void zera() {
    periodoMin = 0xFFFFFFFF;
    periodoMax = 0;
    periodoSoma = 0;
    execMax = 0;
    amostras = 0;
    atrasos = 0;
  }
};
CtlStats ctl;
float servoAngle = 0;

// Aponta o servo: angulo do PROTOCOLO (0 = centro calibrado) + trim.
// writeMicroseconds em vez de write(int): write arredondava para grau
// inteiro, o que somava degraus de 1 grau a folga mecanica.
// Uma linha com TODAS as configuracoes em vigor. Sai no boot, a pedido
// (GET_SETTINGS) e depois de cada SALVAR -- assim o log do Pi registra
// qualquer mudanca feita pelo menu, com hora.
void imprimeSettings() {
  const SettingsData& v = cfg.get();
  Serial.printf(
    "SETTINGS,kp=%.2f,ki=%.2f,kd=%.2f,ticks=%.1f,bcal=%.3f,maxmps=%.2f,"
    "yaww=%.2f,stat=%d,kv=%.1f,limit=%d,wzacc=%.1f,halfl=%.4f,halfw=%.4f,"
    "wheeld=%.4f,imuaxis=%u,imusign=%d,strim=%.2f,vperfil=%u\n",
    v.kp, v.ki, v.kd, v.ticksRev, v.battCal, v.maxWheelMps,
    v.yawEncoderWeight, v.staticPwm, v.kvPwm, v.pwmLimit, v.maxWzAccel,
    v.halfL, v.halfW, v.wheelDiameter, v.imuYawAxis, v.imuYawSign,
    v.servoTrim, v.speedProfile);
}

void servoAponta(float angulo) {
  const float fisico = constrain(angulo + 90.0f + cfg.get().servoTrim,
                                 0.0f, 180.0f);
  const float us = Config::SERVO_US_MIN
                   + fisico * (Config::SERVO_US_MAX - Config::SERVO_US_MIN)
                     / 180.0f;
  servo.writeMicroseconds(lroundf(us));
}
bool test = false;

float ticksPerMeter() {
  return cfg.get().ticksRev / (PI * cfg.get().wheelDiameter);
}

void apply() {
  for (uint8_t i = 0; i < Config::N; i++) {
    pid[i].gains(cfg.get().kp, cfg.get().ki, cfg.get().kd);
  }
}

// Motivo da ultima parada. Sai em DIAG: "o robo parou" sem dizer por que
// ja custou tempo de depuracao -- watchdog, bateria e botao produzem o
// mesmo sintoma visual e exigem acoes opostas.
enum StopReason : uint8_t {
  STOP_NONE = 0,
  STOP_ROS = 1,        // comando STOP pela serial
  STOP_WATCHDOG = 2,   // sem TWIST por CMD_TIMEOUT_MS
  STOP_MENU = 3,       // botao fisico (pressao longa)
  STOP_BATTERY = 4,    // tensao critica
};
uint8_t stopReason = STOP_NONE;

// PARADA DO MENU TRAVADA (24/09/2026). O B1 longo so zerava o comando: com
// a autonomia armada o Pi manda TWIST a 50 Hz e o robo voltava a andar em
// ~20 ms. Agora, depois do B1 longo, todo TWIST e IGNORADO ate o Pi
// confirmar uma acao explicita de voltar a andar: armar de novo
// (CONTROL_STATE,1) ou entrar em SEGUIDOR/RC (MODE_STATE,1 ou 2). O Pi,
// ao receber MENU,STOP, desarma e pede PARADO -- respostas que NAO soltam
// a trava. Sem resposta do Pi, o robo continua parado.
bool paradaTravada = false;

void stop() {
  cmd = {};
  appliedYaw = 0.0f;
  lastCmd = 0;
  test = false;
  motor.stop();
  for (auto& p : pid) {
    p.reset();
  }
  fb.set(LedState::STOPPED);
}

// Historico de contagens para o estimador de velocidade.
//
// POR QUE EXISTE (18/09/2026): a velocidade era (delta ticks)/dt numa
// janela unica de 10 ms. Mesmo com x4 isso da degraus de 0.0186 m/s, e
// o robo anda a 0.07-0.20. Medindo sobre uma janela mais longa o degrau
// cai proporcionalmente: 100 ms levam a ~0.004 m/s.
//
// Duas janelas de proposito. O PID realimenta a curta, porque atraso de
// fase em malha fechada custa mais que ruido. Telemetria e odometria
// usam a longa, porque quem le de fora nao tem como filtrar depois --
// foi exatamente a leitura instantanea quantizada que produziu o falso
// "roda parada" nos diagnosticos de pista.
struct SpeedHist {
  int32_t count[Config::SPEED_HIST][Config::N];
  float t[Config::SPEED_HIST];
  float now = 0.0f;
  uint8_t head = 0;
  uint8_t fill = 0;

  void push(const int32_t c[Config::N], float dt) {
    now += dt;
    head = (head + 1) % Config::SPEED_HIST;
    for (uint8_t i = 0; i < Config::N; i++) {
      count[head][i] = c[i];
    }
    t[head] = now;
    if (fill < Config::SPEED_HIST) {
      fill++;
    }
  }

  // Velocidade da roda sobre os ultimos `win` periodos de controle.
  // Enquanto o buffer nao encheu, usa o que tem -- assim o robo nao
  // passa os primeiros 100 ms sem leitura nenhuma.
  float speed(uint8_t wheel, uint8_t win, float tpm) const {
    uint8_t usar = win;
    if (usar > fill - 1) {
      usar = fill > 1 ? fill - 1 : 0;
    }
    if (usar == 0) {
      return 0.0f;
    }
    const uint8_t old = (head + Config::SPEED_HIST - usar) %
        Config::SPEED_HIST;
    const float dt = t[head] - t[old];
    if (dt <= 1e-6f) {
      return 0.0f;
    }
    return ((count[head][wheel] - count[old][wheel]) / tpm) / dt;
  }
};

void odometry(float dt) {
  static int32_t prev[4] = {};
  static SpeedHist hist;
  const float tpm = ticksPerMeter();
  float d[4];
  for (uint8_t i = 0; i < 4; i++) {
    d[i] = (ws.count[i] - prev[i]) / tpm;
    prev[i] = ws.count[i];
  }
  hist.push(ws.count, dt);
  for (uint8_t i = 0; i < 4; i++) {
    ws.speed[i] = hist.speed(i, Config::SPEED_WIN_PID, tpm);
    ws.speedAvg[i] = hist.speed(i, Config::SPEED_WIN_TEL, tpm);
  }
  // Inversa do modelo direto de control() (mecanum X convencional):
  //   w0 = vx - vy - k*wz     w1 = vx + vy + k*wz
  //   w2 = vx + vy - k*wz     w3 = vx - vy + k*wz
  // Como as colunas sao ortogonais, a inversa e a propria transposta
  // normalizada:
  //   vx -> (+,+,+,+)/4     vy -> (-,+,+,-)/4     wz -> (-,+,-,+)/(4k)
  // Os padroes de vy e wz sao diferentes -- e o que permite separar
  // andar de lado de girar. Na versao anterior os dois eram iguais e
  // essa separacao era impossivel.
  float dx = (d[0] + d[1] + d[2] + d[3]) * 0.25f;
  float dy = (-d[0] + d[1] + d[2] - d[3]) * 0.25f;
  const float k = cfg.get().halfL + cfg.get().halfW;
  float de = (-d[0] + d[1] - d[2] + d[3]) / (4 * k);
  // yawRate, nao gz: a placa da IMU esta em pe e o eixo vertical e o X
  // do chip (gravidade medida em ax = +9.85). Lendo gz o termo girava em
  // ~0 e o yaw integrado andava a 15% da taxa real.
  float dg = imu.state().yawRate * dt;
  float da = imu.state().ready
    ? (1 - cfg.get().yawEncoderWeight) * dg +
      cfg.get().yawEncoderWeight * de
    : de;
  float ym = od.yaw + da * 0.5f;
  od.x += cosf(ym) * dx - sinf(ym) * dy;
  od.y += sinf(ym) * dx + cosf(ym) * dy;
  od.yaw = atan2f(sinf(od.yaw + da), cosf(od.yaw + da));
  // speedAvg (janela longa), nao speed: estes saem na telemetria e o Pi
  // nao tem como desfazer a quantizacao depois.
  od.vx = (ws.speedAvg[0] + ws.speedAvg[1] +
      ws.speedAvg[2] + ws.speedAvg[3]) * 0.25f;
  od.vy = (-ws.speedAvg[0] + ws.speedAvg[1] +
      ws.speedAvg[2] - ws.speedAvg[3]) * 0.25f;

  // GUINADA: giroscopio como fonte primaria, encoder como apoio.
  //
  // JUSTIFICATIVA CORRIGIDA EM 22/09/2026. A anterior dizia que "num
  // mecanum os roletes patinam por projeto" e que por isso o encoder
  // superestimava rotacao. ISSO ESTAVA ERRADO: o robo tinha uma roda
  // montada FORA DO X, e era ela que fazia o robo deslizar ao girar no
  // proprio eixo. Corrigida a montagem, as duas fontes concordam.
  //
  // MEDIDO com o robo no chao, girando por comando em regime:
  //     wz 0.40 -> ganho giro/encoder 1.04
  //     wz 0.80 -> ganho 0.96
  //     wz 1.20 -> ganho 0.94
  // Escala global 0.95: ha patinagem, mas PROGRESSIVA com a velocidade
  // e modesta (6% a 1.2 rad/s), nao um efeito inerente e grande.
  //
  // O peso continua pendendo para o giroscopio, mas agora por RUIDO e
  // nao por vies: o giroscopio tem 0.032 graus/s de ruido e vies que
  // nao deriva (medido: -0.13169 -> -0.13170 em 60 s), enquanto a wz
  // dos encoders herda a quantizacao das quatro rodas. O encoder entra
  // como ancora sem vies, que e o que o giroscopio nao tem.
  //
  // MEDIDO antes de ligar isto: ruido 0.032 graus/s, vies -0.13169
  // rad/s que nao deriva (-0.13170 apos 60 s) e some na calibracao
  // (+0.008 graus/s corrigido). O SINAL foi conferido girando o robo a
  // mao para a direita: 97 de 97 amostras negativas, que e o que a
  // REP-103 manda (z para cima, positivo anti-horario).
  //
  // Isto entra direto no controle: o line_follower_node le
  // twist.twist.angular.z, que e este campo.
  od.wzEnc = (-ws.speedAvg[0] + ws.speedAvg[1] -
      ws.speedAvg[2] + ws.speedAvg[3]) / (4 * k);
  if (imu.state().ready) {
    const float w = cfg.get().yawEncoderWeight;
    od.wz = (1.0f - w) * imu.state().yawRate + w * od.wzEnc;
    // Patinagem MEDIDA, nao inferida. Responde a pergunta que ficou em
    // aberto nas corridas: nos pivos de quebra o comando era wz=-0.90 e
    // o odom lia -0.22 a -0.67, e nao dava para separar "patinou" de
    // "motor nao entregou". A diferenca entre as duas fontes separa.
    od.slip = od.wzEnc - imu.state().yawRate;
  } else {
    od.wz = od.wzEnc;
    od.slip = 0.0f;
  }
}

void control(float dt) {
  enc.read(ws.count);
  imu.update();
  odometry(dt);

  if (millis() - lastCmd > Config::CMD_TIMEOUT_MS) {
    if (cmd.vx != 0.0f || cmd.vy != 0.0f || cmd.wz != 0.0f) {
      stopReason = STOP_WATCHDOG;
    }
    cmd = {};
  }

  const float maxYawStep = cfg.get().maxWzAccel * dt;
  appliedYaw = constrain(
    cmd.wz,
    appliedYaw - maxYawStep,
    appliedYaw + maxYawStep
  );

  float k = cfg.get().halfL + cfg.get().halfW;
  const float lateral = cmd.vy;
  const float yaw = appliedYaw;

  // Mecanum X convencional: roletes apontando para o centro, com
  // FL/RR numa orientacao e FR/RL na outra.
  //
  // Para roda em (a, b) e rolete s = +-1, a cinematica e
  //     u = vx + s*vy + wz*(s*a - b)
  // Com o X correto, s*a - b vale +-(halfL + halfW) nas quatro rodas.
  //
  // HISTORICO: ate a troca das rodas traseiras, os roletes de tras
  // estavam espelhados. Ali o coeficiente de giro real das traseiras
  // caia para (halfL - halfW) = 0.011, mas esta matriz as comandava com
  // (halfL + halfW) = 0.165 -- 15x acima do que elas podiam entregar.
  // O resultado era arrasto lateral das traseiras em toda curva, o que
  // tambem explica o yawEncoderWeight baixo (0.15) herdado: a odometria
  // por encoder nao tinha como concordar com a IMU nesse regime.
  // Com as rodas corrigidas, os quatro coeficientes voltam a ser iguais.
  ws.target[0] = cmd.vx - lateral - k * yaw;  // FL
  ws.target[1] = cmd.vx + lateral + k * yaw;  // FR
  ws.target[2] = cmd.vx + lateral - k * yaw;  // RL
  ws.target[3] = cmd.vx - lateral + k * yaw;  // RR

  for (uint8_t i = 0; i < 4; i++) {
    ws.target[i] = constrain(
      ws.target[i],
      -cfg.get().maxWheelMps,
      cfg.get().maxWheelMps
    );

    if (fabsf(ws.target[i]) < 0.002f) {
      pid[i].reset();
      motor.set(i, 0);
    } else {
      // Feedforward PROPORCIONAL: o degrau vence o atrito estatico e
      // o termo em kv entrega a velocidade pedida. Sem o termo em kv,
      // todo o restante caia no integral, que e lento demais.
      const float mag = cfg.get().staticPwm +
          cfg.get().kvPwm * fabsf(ws.target[i]);
      float ff = ws.target[i] > 0 ? mag : -mag;
      int u = lroundf(constrain(
        ff + pid[i].update(ws.target[i], ws.speed[i], dt),
        -float(cfg.get().pwmLimit),
        float(cfg.get().pwmLimit)
      ));
      if (u != 0 && abs(u) < 45) {
        u = u > 0 ? 45 : -45;
      }
      motor.set(i, u);
    }
    ws.pwm[i] = motor.last(i);

    // Roda travada: pedimos movimento e ela nao anda. Com x1 isto era
    // inutil (a roda lia zero por quantizacao); com x4 + janela longa
    // vira diagnostico de verdade e sai na telemetria.
    if (fabsf(ws.target[i]) > Config::STALL_TARGET &&
        fabsf(ws.speedAvg[i]) < Config::STALL_SPEED) {
      stallSince[i] += lroundf(dt * 1000.0f);
    } else {
      stallSince[i] = 0;
    }
    ws.stalled[i] = stallSince[i] > Config::STALL_MS;
  }
}

// GRUPO RAPIDO: o que o controle do Pi realimenta. 50 Hz.
// Antes tudo saia a 5 Hz, entao a odometria chegava com ate 200 ms de
// idade num laco que decide a 50 Hz.
void telemetryFast() {
  if (millis() - lastTelFast < Config::TELEMETRY_FAST_MS) {
    return;
  }
  lastTelFast = millis();

  Serial.printf(
    "ODOM,%.3f,%.3f,%.3f,%.3f,%.3f,%.3f\n",
    od.x, od.y, od.yaw, od.vx, od.vy, od.wz
  );

  Serial.printf(
    "WHEEL,%.4f,%.4f,%.4f,%.4f\n",
    ws.speedAvg[0], ws.speedAvg[1], ws.speedAvg[2], ws.speedAvg[3]
  );
}

// GRUPO LENTO: diagnostico e coisas que mudam devagar. 5 Hz.
void telemetry() {
  if (millis() - lastTel < Config::TELEMETRY_MS) {
    return;
  }
  lastTel = millis();

  Serial.printf(
    "ENC,%ld,%ld,%ld,%ld\n",
    (long) ws.count[0],
    (long) ws.count[1],
    (long) ws.count[2],
    (long) ws.count[3]
  );

  Serial.printf(
    "TARGET,%.4f,%.4f,%.4f,%.4f\n",
    ws.target[0], ws.target[1], ws.target[2], ws.target[3]
  );

  Serial.printf(
    "PWM,%d,%d,%d,%d\n",
    ws.pwm[0], ws.pwm[1], ws.pwm[2], ws.pwm[3]
  );

  if (imu.state().ready) {
    // O 7o campo e o yawRate: eixo ja escolhido e vies ja removido. Os
    // seis primeiros continuam CRUS de proposito -- e com eles que se
    // descobre a orientacao da placa pela gravidade.
    Serial.printf(
      "IMU,%.4f,%.4f,%.4f,%.4f,%.4f,%.4f,%.4f\n",
      imu.state().ax,
      imu.state().ay,
      imu.state().az,
      imu.state().gx,
      imu.state().gy,
      imu.state().gz,
      imu.state().yawRate
    );
  }

  // Alvo nao-nulo com roda parada. So virou sinal confiavel com x4:
  // com x1 a roda lia zero por quantizacao o tempo todo.
  Serial.printf(
    "STALL,%d,%d,%d,%d\n",
    ws.stalled[0] ? 1 : 0,
    ws.stalled[1] ? 1 : 0,
    ws.stalled[2] ? 1 : 0,
    ws.stalled[3] ? 1 : 0
  );

  Serial.printf("SERVO_STATE,%.2f\n", servoAngle);
  Serial.printf("BATT,%.2f\n", batt.state().voltage);

  // SLIP: wz dos encoders, wz do giroscopio, e a diferenca.
  Serial.printf(
    "SLIP,%.4f,%.4f,%.4f\n",
    od.wzEnc,
    imu.state().ready ? imu.state().yawRate : 0.0f,
    od.slip
  );

  // DIAG: periodo real do controle (us), pico de execucao, e quantos
  // periodos passaram de 15 ms. Alvo e 10000 us com atrasos em zero.
  Serial.printf(
    "DIAG,%lu,%lu,%lu,%lu,%lu,%lu,%u,%lu\n",
    (unsigned long) (ctl.amostras ? ctl.periodoMin : 0),
    (unsigned long) (ctl.amostras ? ctl.periodoSoma / ctl.amostras : 0),
    (unsigned long) ctl.periodoMax,
    (unsigned long) ctl.execMax,
    (unsigned long) ctl.atrasos,
    (unsigned long) ctl.amostras,
    stopReason,
    (unsigned long) serial.rejeitadas()
  );
  // A tela de diagnostico le os mesmos numeros que saem na serial.
  menu.setDiag(ctl.periodoMax, ctl.atrasos, serial.rejeitadas(), stopReason);
  ctl.zera();
}
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
void loop() {
  SerialProtocol::Cmd s;
  while (serial.poll(s)) {
    if (s.type == SerialProtocol::TWIST) {
      // TWIST,vx,vy,wz -- segue geometry_msgs/Twist: vy = lateral,
      // wz = giro (yaw).
      if (!paradaTravada) {
        cmd = {s.a, s.b, s.c};
      }
      lastCmd = millis();   // o link segue vivo mesmo travado
    } else if (s.type == SerialProtocol::STOP) {
      stopReason = STOP_ROS;
      stop();
    } else if (s.type == SerialProtocol::SERVO) {
      servoAngle = constrain(s.a, -90.0f, 90.0f);
      servoAponta(servoAngle);
    } else if (s.type == SerialProtocol::PID) {
      auto& x = cfg.edit();
      x.kp = s.a;
      x.ki = s.b;
      x.kd = s.c;
      apply();
    } else if (s.type == SerialProtocol::SAVE) {
      Serial.println(cfg.save() ? "OK,SAVED" : "ERROR,SAVE");
      imprimeSettings();
    } else if (s.type == SerialProtocol::GET_SETTINGS) {
      imprimeSettings();
    } else if (s.type == SerialProtocol::STATUS) {
      Serial.printf(
        "STATUS,IMU_%s,OLED_%s\n",
        imu.state().ready ? "READY" : "NOT_FOUND",
        menu.inTest() ? "TEST" : "READY"
      );
    } else if (s.type == SerialProtocol::MODE_STATE) {
      menu.setModeFeedback((uint8_t) s.a);
      if (s.a > 0.5f) paradaTravada = false;   // SEGUIDOR ou RC confirmado
    } else if (s.type == SerialProtocol::INFO) {
      menu.setInfo(s.slot, s.text);
    } else if (s.type == SerialProtocol::CONTROL_STATE) {
      menu.setRosControlEnabled(s.a > 0.5f);
      if (s.a > 0.5f) paradaTravada = false;   // rearmado de proposito
    }
  }

  uint32_t now = micros();
  if (now - lastControl >= Config::CONTROL_US) {
    const uint32_t periodoUs = now - lastControl;
    const uint32_t t0 = now;
    float dt = periodoUs * 1e-6f;
    lastControl = now;
    if (dt < 0.1f) {
      if (menu.motorTest()) {
        for (uint8_t i = 0; i < Config::N; i++) {
          motor.set(i, menu.motorTestPwm());
        }
      } else if (menu.servoTest()) {
        // Teste do menu: 90 = centro, agora o CALIBRADO.
        servoAponta(menu.servoTestAngle() - 90.0f);
      } else {
        control(dt);
      }
    }
    ctl.registra(periodoUs, micros() - t0);
  }

  batt.update(cfg.get().battCal);
  MenuAction a = menu.update(cfg);
  if (a == MenuAction::STOP) {
    stopReason = STOP_MENU;
    stop();
    paradaTravada = true;
    servoAponta(0);
    // Tres vezes: o sentido ESP32 -> Pi nao tem CRC nem confirmacao, e o
    // Pi trata o pedido repetido sem efeito colateral.
    for (uint8_t i = 0; i < 3; i++) {
      Serial.println("MENU,STOP");
    }
    fb.beep(1200, 250);
  }
  if (a == MenuAction::RESET_ODOM) {
    od = {};
    fb.beep(1800, 60);
  }
  if (a == MenuAction::RESET_ENCODERS) {
    enc.reset();
    fb.beep(1800, 60);
  }
  if (a == MenuAction::CAL_IMU) {
    stop();
    imu.calibrate();
    fb.beep(2000, 150);
  }
  if (a == MenuAction::SHUTDOWN_PI) {
    // ETAPA 1: so avisa. O Pi anota no log e NAO desliga.
    Serial.println("MENU,SHUTDOWN_REQ");
    fb.beep(1500, 200);
  }
  // Rearma a tela depois do pedido, para dar para testar varias vezes
  // seguidas sem sair e voltar no menu.
  //
  // 1200 ms (era 4000). MEDIDO: com 4 s, cinco toques seguidos do
  // operador viraram DOIS pedidos -- os outros tres caiam dentro da
  // janela e sumiam em silencio, que faz parecer que funcionou quando
  // metade se perdeu. 1200 ms ainda e muito acima de repique de botao
  // (dezenas de ms), entao um toque continua valendo um pedido.
  if (menu.shutdownState() == LocalMenu::Shutdown::PEDIDO &&
      millis() - menu.shutdownAge() > 1200) {
    menu.rearmaShutdown();
  }
  if (a == MenuAction::SET_MODE) {
    // O ESP32 PEDE o modo; quem manda de fato e o Pi, que responde com
    // MODE_STATE. Assim a tela nunca anuncia um modo que o Pi nao esta
    // executando -- por exemplo se o no do joystick nem estiver no ar.
    Serial.printf("MENU,MODE,%u\n", menu.modeRequested());
    fb.beep(2000, 80);
  }
  if (a == MenuAction::TOGGLE_ROS_CONTROL) {
    Serial.println("MENU,CONTROL_TOGGLE");
    fb.beep(2000, 100);
  }
  if (a == MenuAction::SAVE) {
    apply();
    fb.beep(2200, 90);
    Serial.println(cfg.save() ? "OK,SAVED" : "ERROR,SAVE");
    imprimeSettings();
  }

  if (menu.inTest() && !menu.motorTest() && !menu.servoTest()) {
    motor.stop();
  }

  bool ros = millis() - lastCmd < Config::CMD_TIMEOUT_MS;
  if (batt.state().critical) {
    stopReason = STOP_BATTERY;
    fb.set(LedState::BATTERY_CRITICAL);
  } else if (batt.state().low) {
    fb.set(LedState::BATTERY_LOW);
  } else if (paradaTravada) {
    fb.set(LedState::STOPPED);
  } else if (menu.editing()) {
    fb.set(LedState::MENU);
  } else {
    fb.set(
      ros
        ? LedState::RUN
        : LedState::IDLE
    );
  }

  fb.update();
  // "Andando" = ha comando de movimento de fato, com histerese de 1 s
  // para a tela nao piscar em cada parada curta de curva.
  const bool comandado = fabsf(cmd.vx) > 0.005f ||
      fabsf(cmd.vy) > 0.005f || fabsf(cmd.wz) > 0.01f;
  if (comandado) {
    lastMoving = millis();
  }
  const bool moving = lastMoving != 0 && millis() - lastMoving < 1000;
  menu.draw(batt.state(), ws, od, imu.state(), cfg, ros, moving);
  telemetryFast();
  telemetry();
}

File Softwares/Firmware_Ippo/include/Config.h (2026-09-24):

#pragma once

#include <Arduino.h>

namespace Config {

constexpr char NAME[] = "ESP32S3_OMNI_LINE";
constexpr uint8_t N = 4;

enum Wheel : uint8_t {
  FL = 0,
  FR = 1,
  RL = 2,
  RR = 3,
};

constexpr uint8_t IN1[N] = {5, 39, 8, 47};   //5, 39, 8, 47
constexpr uint8_t IN2[N] = {4, 40, 9, 16};   //4, 40, 9, 16
constexpr uint8_t ENCA[N] = {6, 42, 11, 21};  //6, 42, 11, 21
constexpr uint8_t ENCB[N] = {7, 41, 10, 18};   //7, 41, 10, 18
constexpr int8_t MOTOR_SIGN[N] = {1, 1, 1, 1};
constexpr int8_t ENC_SIGN[N] = {1, 1, 1, 1};

constexpr uint8_t BTN1 = 12;
constexpr uint8_t BTN2 = 14;
constexpr uint8_t SERVO = 13;
constexpr uint8_t BATT = 15;
constexpr uint8_t BUZZER = 45;
constexpr uint8_t RGB = 48;

constexpr uint8_t SDA = 1;
constexpr uint8_t SCL = 2;
constexpr uint8_t MPU_ADDR = 0x68;
constexpr uint8_t OLED_ADDR = 0x3C;

constexpr uint32_t I2C_HZ = 400000;
constexpr uint32_t CONTROL_US = 10000;

// Versao do esquema de Settings gravado em NVS. INCREMENTE sempre que o
// SIGNIFICADO de um campo mudar -- sem isso o valor antigo continua em
// NVS e o default novo nunca pega. A v2 marca a troca dos encoders para
// decodificacao x4, que multiplica ticksRev por 4.
// v4 (24/09/2026): MAX VELOCIDADE acima de 1.0 m/s volta ao default --
// o menu deixava ir a 2.0, o que desliga na pratica a saturacao por roda
// do firmware (achado em NVS com 2.00, sem registro de quem mudou).
constexpr uint32_t SETTINGS_VERSION = 4;

// Baud da UART para o CH343. MEDIDO em 10/09/2026: a telemetria antiga
// (209 B a 5 Hz) ocupava 9.1% de 115200. Com ODOM/WHEEL a 50 Hz o uso
// iria a 55%, apertado; a 921600 fica em 7%.
constexpr uint32_t SERIAL_BAUD = 921600;
// Telemetria em DOIS grupos. O controle roda a 100 Hz e o controlador do
// Pi a 50 Hz, mas tudo chegava a 5 Hz -- odometria com ate 200 ms de
// idade. Agora o que o controle usa vai rapido e o resto continua lento.
constexpr uint32_t TELEMETRY_MS = 200;       // ENC, TARGET, PWM, IMU, SERVO, BATT
constexpr uint32_t TELEMETRY_FAST_MS = 20;   // ODOM, WHEEL  (50 Hz)
constexpr uint32_t OLED_MS = 500;
constexpr uint32_t CMD_TIMEOUT_MS = 200;

constexpr uint32_t MOTOR_PWM_HZ = 20000;
constexpr uint8_t MOTOR_PWM_BITS = 8;
constexpr int PWM_MAX = 255;
// FEEDFORWARD DA MALHA DE VELOCIDADE, medido em 22/09/2026.
//
// O antigo era um degrau FIXO de 100 PWM em qualquer velocidade. Medindo
// o motor sob carga (robo girando no proprio eixo, no chao):
//
//     PWM 138 -> roda faz 0.0136 m/s      PWM 158 -> 0.1820 m/s
//     ajuste: v = 0.00857*pwm - 1.1797
//     limiar de atrito 138 PWM   ganho 117 PWM por m/s
//
// Ou seja, os 100 PWM ficavam 38 ABAIXO do ponto em que a roda comeca a
// andar. Quem cobria a diferenca era o integral, e ele leva ~10 s para
// somar os 36 PWM que faltam com o erro tipico -- num seguidor cujo
// comando muda toda hora, ele nunca chega la. Era isso que fazia a
// entrega cair para 27% do pedido em giro lento.
//
// Agora o feedforward acompanha o alvo:  ff = STATIC + KV * |alvo|
//
// ATENCAO: estes numeros foram medidos GIRANDO NO CHAO, que e a carga
// mais pesada (os roletes raspam de lado). Andando em linha reta a carga
// e menor, entao o ff sobra um pouco e o PID corrige para baixo -- que e
// o lado seguro para errar.
constexpr int STATIC_PWM_DEFAULT = 138;
constexpr float KV_PWM_DEFAULT = 117.0f;

// 200 (era 180). Com o ff proporcional, 0.30 m/s ja pede 173 PWM e
// sobrariam 7 para o PID corrigir -- apertado demais. 200 de 255 e 78%
// de duty, com folga para o PID sem forcar o motor.
constexpr int PWM_LIMIT_DEFAULT = 200;

constexpr float WHEEL_D_M = 0.078f;
constexpr float WHEEL_C = PI * WHEEL_D_M;
// x4: o PCNT conta as duas bordas dos DOIS canais (ver EncoderManager).
//
// POR QUE MUDOU (18/09/2026): com x1 e janela de 10 ms a velocidade de
// roda so podia valer 0, 0.074, 0.149... e o robo trabalha entre 0.07 e
// 0.20 m/s. A roda direita, a 0.106 m/s, da 1.43 ticks por janela --
// abaixo de 1 ela le EXATAMENTE ZERO girando perfeitamente. Foi isso, e
// nao falha mecanica, que produziu o "roda parada" nos diagnosticos.
//
// x4 leva a quantizacao para 0.0186 m/s. Combinado com a janela mais
// longa do estimador (ver SPEED_WIN_*), a telemetria chega a ~0.004.
constexpr float TICKS_REV_DEFAULT = 1320.0f;

// Janelas do estimador de velocidade, em periodos de controle (10 ms).
// Curta para o PID (realimentacao rapida), longa para telemetria e
// odometria (leitura limpa). Sao independentes de proposito: o PID
// aguenta ruido, quem le do lado de fora nao.
constexpr uint8_t SPEED_WIN_PID = 3;    //  30 ms
constexpr uint8_t SPEED_WIN_TEL = 10;   // 100 ms
constexpr uint8_t SPEED_HIST = 16;      // tamanho do buffer circular
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

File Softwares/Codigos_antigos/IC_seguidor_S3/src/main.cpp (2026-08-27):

  #include <Arduino.h>
  #include <Wire.h>
  #include <driver/pcnt.h>
  #include <Adafruit_MPU6050.h>
  #include <Adafruit_Sensor.h>
  #include <math.h>

  // ============================================================
  // ESP32-S3 DevKitC-1 N16R8
  // Ordem lógica / cinemática:
  // M1 = frente-esquerda (FL)
  // M2 = frente-direita  (FR)
  // M3 = traseira-esquerda (RL)
  // M4 = traseira-direita  (RR)
  // USB nativo: GPIO19 / GPIO20 reservados
  // RGB onboard: GPIO38 ou GPIO48 reservados
  // I2C IMU: SDA=GPIO1, SCL=GPIO2
  // ============================================================

  // Pinagem soldada
  constexpr uint8_t MOTOR_IN1[4] = {
    8,   // M1 FL
    5,   // M2 FR
    47,  // M3 RL
    39   // M4 RR
  };

  constexpr uint8_t MOTOR_IN2[4] = {
    9,   // M1 FL
    4,   // M2 FR
    16,  // M3 RL
    40   // M4 RR
  };

  constexpr uint8_t ENC[_A[4] = {
    10,  // M1 FL
    6,   // M2 FR
    21,  // M3 RL
    41   // M4 RR
  };

  constexpr uint8_t ENC_B[4] = {
    11,  // M1 FL
    7,   // M2 FR
    18,  // M3 RL
    42   // M4 RR
  };

  constexpr pcnt_unit_t PCNT_UNIT[4] = {
    PCNT_UNIT_0,
    PCNT_UNIT_1,
    PCNT_UNIT_2,
    PCNT_UNIT_3
  };

  // Ajuste estes sinais após validar cada roda.
  // Em TWIST frente (+vx), todas as rodas devem tracionar para frente
  // e todos os encoders devem aumentar.
  constexpr int8_t MOTOR_SIGN[4] = {1, 1, 1, 1};
  constexpr int8_t ENCODER_SIGN[4] = {1, 1, 1, 1};

  // Geometria e encoder
  constexpr float WHEEL_DIAMETER_M = 0.078f;
  constexpr float ENCODER_TICKS_PER_WHEEL_REV = 330.0f;
  constexpr float WHEEL_CIRCUMFERENCE_M = PI * WHEEL_DIAMETER_M;
  constexpr float TICKS_PER_METER = ENCODER_TICKS_PER_WHEEL_REV / WHEEL_CIRCUMFERENCE_M;

  // Meça no chassi real e ajuste se necessário.
  constexpr float ROBOT_HALF_LENGTH_M = 0.105f;
  constexpr float ROBOT_HALF_WIDTH_M = 0.090f;
  constexpr float KINEMATIC_K = ROBOT_HALF_LENGTH_M + ROBOT_HALF_WIDTH_M;

  // Controle e telemetria
  constexpr uint32_t CONTROL_PERIOD_US = 10000;   // 100 Hz
  constexpr uint32_t TELEMETRY_PERIOD_MS = 50;    // 20 Hz
  constexpr uint32_t COMMAND_TIMEOUT_MS = 400;

  constexpr int PWM_LIMIT = 180;
  constexpr int PWM_STATIC = 100;                 // ajuste 90..140 para vencer atrito estático
  constexpr float MAX_WHEEL_SPEED_MPS = 0.70f;

  // PID de velocidade: ponto de partida com feedforward estático.
  constexpr float KP = 120.0f;
  constexpr float KI = 100.0f;
  constexpr float KD = 5.0f;
  constexpr float INTEGRAL_LIMIT = 1.2f;

  // IMU e fusão de yaw
  constexpr float YAW_ENCODER_WEIGHT = 0.15f;
  constexpr float ACCEL_FILTER_ALPHA = 0.20f;

  Adafruit_MPU6050 mpu;
  bool imuReady = false;

  int32_t encoderCount[4] = {0, 0, 0, 0};
  int32_t encoderPrevious[4] = {0, 0, 0, 0};
  float wheelSpeedMps[4] = {0, 0, 0, 0};
  float wheelTargetMps[4] = {0, 0, 0, 0};
  float pidIntegral[4] = {0, 0, 0, 0};
  float pidLastError[4] = {0, 0, 0, 0};

  float vxCommand = 0.0f;
  float vyCommand = 0.0f;
  float wzCommand = 0.0f;
  uint32_t lastCommandMs = 0;

  float odomX = 0.0f;
  float odomY = 0.0f;
  float odomYaw = 0.0f;
  float gyroZBias = 0.0f;
  float gyroZRadps = 0.0f;
  float accelX = 0.0f;
  float accelY = 0.0f;
  float accelZ = 0.0f;

  uint32_t lastControlUs = 0;
  uint32_t lastTelemetryMs = 0;
  String lineBuffer;

  void setMotor(uint8_t index, int pwm) {
    pwm *= MOTOR_SIGN[index];
    pwm = constrain(pwm, -PWM_LIMIT, PWM_LIMIT);

    if (pwm > 0) {
      analogWrite(MOTOR_IN1[index], pwm);
      analogWrite(MOTOR_IN2[index], 0);
    } else if (pwm < 0) {
      analogWrite(MOTOR_IN1[index], 0);
      analogWrite(MOTOR_IN2[index], -pwm);
    } else {
      analogWrite(MOTOR_IN1[index], 0);
      analogWrite(MOTOR_IN2[index], 0);
    }
  }

  void stopMotors() {
    for (uint8_t i = 0; i < 4; ++i) setMotor(i, 0);
  }

  void setupEncoder(uint8_t index, int pinA, int pinB) {
    pcnt_config_t config = {};
    config.pulse_gpio_num = pinA;
    config.ctrl_gpio_num = pinB;
    config.unit = PCNT_UNIT[index];
    config.channel = PCNT_CHANNEL_0;

    // Quadratura x1: subida em A conta, B define o sentido.
    config.pos_mode = PCNT_COUNT_INC;
    config.neg_mode = PCNT_COUNT_DIS;
    config.lctrl_mode = PCNT_MODE_REVERSE;
    config.hctrl_mode = PCNT_MODE_KEEP;
    config.counter_h_lim = 32767;
    config.counter_l_lim = -32768;

    ESP_ERROR_CHECK(pcnt_unit_config(&config));
    ESP_ERROR_CHECK(pcnt_set_filter_value(PCNT_UNIT[index], 1000));
    ESP_ERROR_CHECK(pcnt_filter_enable(PCNT_UNIT[index]));
    ESP_ERROR_CHECK(pcnt_counter_pause(PCNT_UNIT[index]));
    ESP_ERROR_CHECK(pcnt_counter_clear(PCNT_UNIT[index]));
    ESP_ERROR_CHECK(pcnt_counter_resume(PCNT_UNIT[index]));
  }

  void readEncoders() {
    for (uint8_t i = 0; i < 4; ++i) {
      int16_t rawCount = 0;
      ESP_ERROR_CHECK(pcnt_get_counter_value(PCNT_UNIT[i], &rawCount));
      encoderCount[i] = static_cast<int32_t>(rawCount) * ENCODER_SIGN[i];
    }
  }

  void updateImu() {
    if (!imuReady) return;

    sensors_event_t accel, gyro, temperature;
    mpu.getEvent(&accel, &gyro, &temperature);

    gyroZRadps = gyro.gyro.z - gyroZBias;
    accelX += ACCEL_FILTER_ALPHA * (accel.acceleration.x - accelX);
    accelY += ACCEL_FILTER_ALPHA * (accel.acceleration.y - accelY);
    accelZ += ACCEL_FILTER_ALPHA * (accel.acceleration.z - accelZ);
  }

  void calibrateGyro() {
    if (!imuReady) return;

    constexpr int SAMPLES = 500;
    float sumZ = 0.0f;
    sensors_event_t accel, gyro, temperature;

    for (int i = 0; i < SAMPLES; ++i) {
      mpu.getEvent(&accel, &gyro, &temperature);
      sumZ += gyro.gyro.z;
      delay(3);
    }
    gyroZBias = sumZ / static_cast<float>(SAMPLES);
  }
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

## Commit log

2026-08-27 Update README with ROS 2 Jazzy camera setup instructions
    This document provides essential commands for setting up and using a USB camera on Raspberry Pi with ROS 2 Jazzy, including installation, image visualization, and remote access.
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2026-08-29 Revise readme for clarity and detail improvements
    Updated the readme with corrections and additional details for camera setup and control commands.
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2026-09-18 Software: firmware 2.0 e arquitetura ROS nova
    Substitui a primeira arquitetura (line_control / line_vision /
    IC_seguidor_S3), movida para Softwares/Codigos_antigos como registro.
    FIRMWARE (ESP32-S3)
    - Encoders em quadratura x4. Com x1 e janela de 10 ms a velocidade de
    roda so podia valer multiplos de 0.074 m/s, e o robo anda entre 0.07 e
    0.20: uma roda a 0.106 m/s lia ZERO por quantizacao. Era isso, e nao
    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
    [corrida_20260910_193825.csv, corrida_20260910_203230.csv]
2026-09-18 Escreve o README da raiz
    O README principal estava vazio -- era a primeira coisa que alguem via
    ao abrir o repositorio.
    Descreve a arquitetura de visao dupla, as especificacoes do chassi e da
    eletronica, os tres modos de operacao e os resultados medidos em pista,
    com ponteiros para o guia de operacao em Softwares/ros2_ws.
2026-09-19 Mover arquivos da Mecânica para Base Mecanum
    [chassi migo base.f3d]
2026-09-24 ros2_ws: sincroniza com o robo (estado de 22/09)
    Trabalho de 19 a 22/09 que estava so no Pi.
    - line_controller: memoria do lado visto pela camera superior
    (preview_memory_time), com o lateral projetado pelo heading; vale so
    em RECOVERING e so define o lado do giro.
    - mode_manager: pedidos de parametro reenfileirados enquanto o no de
    destino nao tem servico; body_control_enabled nasce False.
    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
2026-09-24 ros2_ws: correcoes de seguranca e de controle (revisao de 24/09)
    Seguranca
    - corrida.py: Ctrl-C agora desliga a autonomia. O handler de sinal do
    rclpy fechava o contexto antes do finally, e enable(False) e PARADO
    lancavam RCLError: o robo ficava armado em SEGUIDOR. Desligar publica
    na hora, sem esperar assinantes, e o CSV e gravado mesmo interrompido.
    - Scripts de servo (servo_panorama, servo_prova, varredura,
    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
2026-09-24 ros2_ws: recalibra o offset do servo e conserta liga_autonomia
    - servo_offset_deg -3.0 -> +7.0. Com o suporte realinhado, a superior
    media +14.7 graus de heading numa reta em que a inferior media -1.2.
    Varredura do pan nos dois sentidos medindo as duas cameras: a
    diferenca de heading cruza zero em +10.7 subindo e +8.8 descendo.
    Conferido depois do reinicio: centro real a -0.4 graus; o que sobra
    (+5.9 / -3.7 graus conforme o lado de chegada) e folga do servo.
    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
2026-09-24 ros2_ws: memoria de freio do preview e mapa do circuito
    Memoria de freio
    - corrida_20260924_112344 (5 quebras): a superior avisa ~17 cm antes e
    o robo freia a v_min, mas o freio soltava faltando 12-16 cm -- a
    cabeca gira para rastrear a quebra (passa de preview_center_tol_deg)
    ou a confianca cai abaixo de preview_confidence_min. Chegava na quina
    a 0.11-0.18 m/s e perdeu a linha em 2 das 5.
    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
2026-09-24 Firmware_Ippo: sincroniza com o robo (estado de 22/09)
    Trabalho que estava so no Pi.
    - Feedforward da malha de velocidade proporcional ao alvo
    (ff = STATIC_PWM + KV_PWM * |alvo|, medidos em 22/09: 138 PWM e
    117 PWM por m/s), no lugar do degrau fixo de 100 PWM que ficava abaixo
    do limiar de atrito. PWM_LIMIT 180 -> 200.
    - Settings v3 com migracao: os valores antigos de feedforward em NVS
    voltam ao default novo.
    - Menu: pedido de desligamento da Raspberry com confirmacao por toque
    curto; nesta etapa o Pi so registra o pedido.
    [Config.h, LocalMenu.cpp, LocalMenu.h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]
2026-09-24 Firmware_Ippo: trim do servo em NVS; gravar.sh respeita o robo.service
    Firmware
    - Settings.servoTrim (chave NVS "strim", default -7.0 graus fisicos),
    somado a TODO comando do servo: boot, STOP do menu, SERVO,a do Pi e
    teste do menu. A cabeca nasce no centro calibrado -- antes o boot e o
    STOP iam ao centro mecanico e ficavam ~7 graus tortos ate o Pi mandar
    o primeiro comando. Chave nova com default: sem mudar a versao.
    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
2026-09-24 Firmware_Ippo: GET_SETTINGS, perfil de velocidade no menu e teto por roda
    - GET_SETTINGS devolve uma linha SETTINGS,kp=...,strim=...,vperfil=...
    com todas as configuracoes em vigor. Sai tambem no boot e depois de
    cada SALVAR (menu ou serial), entao o log do Pi registra qualquer
    ajuste feito pelo OLED. Motivo: em 24/09 um SERVO TRIM "salvo" nao
    tinha sido salvo, e so deu para descobrir medindo o efeito.
    - CONFIG > VELOCIDADE: SUAVE / MEDIA / RAPIDA, gravado em NVS (chave
    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
2026-09-24 ros2_ws: sobe os tres perfis de velocidade em ~10-15%
    SUAVE MEDIA RAPIDA
    v_min 0.07 -> 0.08 0.09 -> 0.10 0.11 -> 0.12
    v_max 0.22 -> 0.25 0.28 -> 0.32 0.40 -> 0.44
    - Base: corrida_20260924_132830 (MEDIA, memoria de freio corrigida):
    retas a 0.143, maximo 0.26 com v_max 0.28 quase atingido.
    - Risco conhecido: as 4 recuperacoes dessa corrida foram todas em v_min
    com a cabeca travada em +45 graus (quinas fechadas). Subir v_min
    aumenta esse risco; v_max nao. RAPIDA 0.44 fica sob max_vx 0.45 do
    motor_serial_node.
    - v_min/v_max do line_follower_node (valem ate o perfil chegar) iguais
    ao SUAVE novo; defaults do mode_manager_node iguais ao YAML.
    [line_follower.yaml, mode_manager_node.py]
2026-09-24 dados: corridas de 24/09 citadas nos commits do dia
    Seis CSVs do scripts/corrida.py (3,3 MB) -- os numeros das mensagens de
    commit de hoje (memoria de freio, curvatura-ruido da superior, perfis
    de velocidade) saem deles, pelo replay ou pelo tools/mapa.py.
    Ultima: RAPIDA (v_min 0.12, v_max 0.44), 3 min: vx medio 0.168 (MEDIA
    0.124), retas 0.209, max 0.371, volta 58 s, mapa fecha em 4.5 cm. 8
    recuperacoes de 0.38 a 0.76 s, nenhuma parada de seguranca; 7 delas em
    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
    [corrida_20260924_112344.csv, corrida_20260924_120518.csv, corrida_20260924_130437.csv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]
2026-09-24 docs: guia de operacao (OPERACAO.md) e README corrigido
    OPERACAO.md novo, conferido contra o codigo de 24/09 (firmware 2.0.0):
    parar o robo, pilha pelo robo.service (start/stop/restart, log, nos
    esperados), modos pelo menu e pelo ROS (logs/modo.py, ros2 topic pub -t),
    armar/desarmar a autonomia com confirmacao, perfil de velocidade, corrida
    e mapa, menu do ESP32 (botoes, abas, CONFIG, TESTES), resets (odometria,
    encoders, IMU, ESP32, pilha, DDS, Pi), desligar a Raspberry, gravar
    firmware, calibracoes (trim do servo, bateria), joystick, ferramentas
    (marcando as que movem o robo), problemas comuns e referencia rapida.
    Correcoes no README que hoje ensinavam errado:
    - "Subir o sistema" mandava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
